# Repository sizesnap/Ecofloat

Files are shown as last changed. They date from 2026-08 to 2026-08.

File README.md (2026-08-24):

# EcoFloat

An autonomous catamaran that maps dissolved oxygen and temperature across a lake and hands back a georeferenced picture of where the water is actually in trouble.

download (1) (1)

Traditional monitoring pulls a handful of point samples and calls it a lake. EcoFloat runs a GPS waypoint mission, logs DO and temperature continuously along the track, and turns that into a spatial map. On its first real survey it found two zones that point sampling would have missed entirely.

---

## Field results — Deep Quarry Lake, July 29 2026

Deep Quarry Lake, West Branch Forest Preserve, DuPage County IL (~40 acres, ~45 ft max depth). Run under a research permit from the Forest Preserve District of DuPage County.

- **2,862** georeferenced DO + temperature readings in a single morning session
- **Low-DO zone** along the northeastern shore, down to **4.72 mg/L**
- **Supersaturation zone** along the western shore, up to **9.75 mg/L**

That's a ~5 mg/L spread across one small lake. A single grab sample anywhere in the middle reports none of it.

DeepQuarry lake Survey map 7_29_2026

---

## How it works



**Navigation** — ArduRover 4.6.3 on a CoreWing F405 Wing V2. Differential skid steer from two ApisQueen U2 12V thrusters driven by DH 40A ESCs. Missions upload as GPS waypoints and run in Auto with no operator input.

**Sensor pod** — ESP32-S3 (Heltec WiFi LoRa 32 V3) polls a DFRobot SEN0680 optical DO sensor over RS485/Modbus, stamps each reading with a fix from a BZ-251 GPS, writes to a 3,000-reading circular buffer on device, and streams telemetry to shore over LoRa.

**Shore station** — a second Heltec V3 receives the LoRa stream and serves a WiFi access point with a Leaflet map: live DO-colored breadcrumbs over satellite imagery, CSV download, and KML mission upload to LittleFS.



**Hull** — custom composite fiberglass layup, twin hulls on a cross-tube bracket system, one 3S LiPo per hull wired in parallel. High-visibility orange and white, because a lost boat 200m out is a bad afternoon.

---

## Bill of materials

Full parts list with quantities, costs, vendor links, and build notes: **[`BOM.csv`](BOM.csv)**

Headline numbers — approximately **$753** total, of which the DFRobot SEN0680 optical DO sensor is $199. Everything else is off-the-shelf hobby-grade hardware or hardware-store consumables.

---|---|---|---|---|
| DFRobot SEN0680 RS485 fluorescence DO sensor (freshwater) | 1 | Dissolved oxygen + temperature, 0–20 mg/L, ModBus-RTU, IP68 | $199 | [DFRobot wiki](https://wiki.dfrobot.com/SKU_SEN0680_RS485_Dissolved_Oxygen_Sensor_Freshwater) · [DigiKey](https://www.digikey.com/en/products/detail/dfrobot/SEN0680/28531158) |
| DFRobot DFR0845 active isolated RS485↔UART adapter | 1 | Bridges the Modbus sensor to the ESP32; supplies 12V to the probe | ~$14 | DFRobot |
| Heltec WiFi LoRa 32 V3 (ESP32-S3 + SX1262) | 2 | Boat sensor pod + shore base station | ~$25 ea | [Heltec](https://heltec.org/project/wifi-lora-32-v3/) · [Rokland](https://store.rokland.com/products/heltec-wifi-lora-32v3) |
| 915 MHz LoRa antenna | 2 | Telemetry link, boat ↔ shore | ~$6 ea | included with board |
| BZ-251 GPS module | 1 | Position fix for each reading | ~$20 | *add your order link* |
| ApisQueen U2 12V underwater thruster (CW + CCW) | 2 | Differential skid-steer propulsion, ~1.7 kg thrust each | ~$85 ea | [ApisQueen](https://www.underwaterthruster.com/products/apisqueen-u2-12v-150w-underwaterthruster-with-esc-5v-1a-bec-output-for-rov-boat) |
| DH 40A bidirectional ESC | 2 | Thruster drive, forward/reverse | ~$20 ea | *add your order link* |
| CoreWing F405 Wing V2 flight controller | 1 | Runs ArduRover 4.6.3, autonomous waypoint navigation | ~$45 | *add your order link* |
| 3S LiPo battery | 2 | One per hull, wired in parallel | ~$30 ea | *add your order link* |
| RadioMaster T8L transmitter + ELRS receiver | 1 | Manual override / failsafe control | ~$45 | *add your order link* |
| Fiberglass cloth + epoxy resin | — | Composite hull layup | ~$60 | local / hardware store |
| Aluminum cross tubes | 2 | Hull-to-hull structure | ~$15 | local / hardware store |
| 3D-printed brackets and electronics trays | — | Resin (Elegoo Saturn 4 Ultra) + FDM; STLs in `hardware/` | ~$10 in resin/filament | printed in-house |
| Marine paint, orange + white | — | High-visibility finish | ~$25 | local / hardware store |

Rough build total: **~$700**, with the DO sensor about a third of it.

---

## Repo layout

```
firmware/
  EcoFloat_Boat/        ESP32-S3 sensor + GPS + LoRa TX
  EcoFloat_Base/        Heltec V3 receiver, web server, Leaflet dashboard
hardware/               CAD sources, STEP, STL
analysis/
  ecofloat_to_kml.py    CSV to Google Earth KML
missions/               KML waypoint mission files
data/                   Survey CSVs
docs/                   Photos, diagrams, build notes
```

Each `.ino` sits in a folder of the same name — an Arduino requirement, so the sketches open cleanly straight from a clone.

---

## Post-processing

`ecofloat_to_kml.py` turns logged CSVs into a Google Earth layer:

```bash
python3 analysis/ecofloat_to_kml.py
```

It auto-discovers CSVs in `~/Downloads/Ecofloat data`, filters GPS jitter and zero-length segments from stationary fixes, and writes KML with color-coded track segments plus a filled disc polygon per reading.

Open the output in **Google Earth Pro (desktop)**. The web version rejects files past its geometry count limit.

---

## Notes from the build

Things that cost real time, recorded so they don't cost anyone else's:

- **Calibrate the compass in its final mounted position.** A bad or missing calibration means Auto mode picks a heading at random the instant you switch into it.
- **Never connect the red BEC wire from an ESC servo lead to the flight controller servo rail.** It backfeeds 5V and causes a power surge. Signal and ground only.
- **DO below ~3.5 mg/L usually means the sensor is out of the water**, not that the lake is dead — that reading is physically impossible in an aerated lake. It's the most reliable air-exposure flag for cleaning merged datasets.
- **The RS485 T/R lines are easy to reverse.** Swapped pins hold the line at ~1V instead of switching cleanly to ground, and the sensor returns zero bytes with no error message at all.
- GPS TX/RX crossover, tube OD tolerances, and hull-to-hull variation in a hand layup all bit at least once. Measure before you print.

---

## Roadmap

- Weekly repeat surveys — Sept 5, 12, 19, 26 and an Oct 10 turnover follow-up, same mission file, same morning window, weather covariates logged each run
- Expansion to Herrick Lake and Rice Lake, pending Forest Preserve coordination
- Additional parameters under evaluation: pH, turbidity, conductivity
- Interpolated heat maps (`scipy.griddata`) plus statistical analysis — ANOVA across zones, regression of DO against temperature and distance from shore

---

## Acknowledgments

Dan Grigas, Fisheries Ecologist at the Forest Preserve District of DuPage County, for the research permit, site access, and ongoing collaboration.

## License

TBD — see repository owner before reuse.

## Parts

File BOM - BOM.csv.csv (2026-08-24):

Item | Qty | Purpose | Unit Cost USD | Line Total USD | Cost Source | Vendor | Link | Notes
DFRobot SEN0680 RS485 Fluorescence Dissolved Oxygen Sensor (Freshwater) | 1 | Dissolved oxygen and temperature, 0-20 mg/L, ModBus-RTU, IP68, 316 stainless probe | 199 | 199 | List price - NOT on cost sheet | DFRobot | https://wiki.dfrobot.com/SKU_SEN0680_RS485_Dissolved_Oxygen_Sensor_Freshwater | Also at DigiKey: https://www.digikey.com/en/products/detail/dfrobot/SEN0680/28531158 . Factory pre-calibrated; zero and full-scale recalibration via register writes.
DFRobot DFR0845 Active Isolated RS485-to-UART Adapter | 1 | Bridges the Modbus DO sensor to the ESP32 and supplies 12V to the probe | 14 | 14 | Estimate - NOT on cost sheet | DFRobot |  | T/R lines are easy to reverse - swapped pins hold the bus at ~1V and the sensor returns zero bytes with no error.
Heltec WiFi LoRa 32 V3 (ESP32-S3 + SX1262) 2-pack | 2 | Boat sensor pod and shore base station | 19.5 | 38.99 | Cost sheet | Heltec | https://store.rokland.com/products/heltec-wifi-lora-32v3 | 915 MHz (US). Flash as generic ESP32S3 Dev Module, Flash Size 8MB, partition scheme with SPIFFS.
915 MHz LoRa antenna | 1 | Telemetry link between boat and shore | 12.99 | 12.99 | Cost sheet
Betian 9th Gen Beidou BK-250P GPS module | 1 | Position fix stamped onto every sensor reading | 29.88 | 29.88 | Cost sheet | Betian |  | TX line to GPIO 26 - avoid GPIO 46, it is a strapping pin and blocks USB uploads.
ApisQueen U2 12V Underwater Thruster (CCW) | 1 | Port-side propulsion, differential skid steer | 43.98 | 43.98 | Cost sheet | ApisQueen | https://www.underwaterthruster.com/products/apisqueen-u2-12v-150w-underwaterthruster-with-esc-5v-1a-bec-output-for-rov-boat | 12-16V (3-4S LiPo), 150W, composite housing, fresh and salt water rated.
ApisQueen U2 12V Underwater Thruster (CW) | 1 | Starboard-side propulsion, differential skid steer | 43.98 | 43.98 | Cost sheet | ApisQueen | https://www.underwaterthruster.com/products/apisqueen-u2-12v-150w-underwaterthruster-with-esc-5v-1a-bec-output-for-rov-boat
DH 40A bidirectional ESC | 2 | Thruster drive, forward and reverse | 21.99 | 43.98 | Cost sheet |  |  | Do NOT connect the red BEC wire from the servo lead to the FC servo rail - it backfeeds 5V. Signal and ground only.
CoreWing F405 Wing V2 flight controller | 1 | Runs ArduRover 4.6.3, autonomous GPS waypoint missions | 45 | 45 | Estimate - NOT on cost sheet |  |  | Compass must be calibrated in its final mounted position or Auto mode picks a random heading on mode switch.
3S LiPo battery (propulsion) | 2 | One per hull, wired in parallel | 30 | 60 | Estimate - NOT on cost sheet |  |  | Endurance approximately 45-65 minutes per survey.
LiPo battery (sensor pod) | 1 | Powers the boat-side Heltec V3 | 12.99 | 12.99 | Cost sheet
RadioMaster T8L transmitter + ELRS receiver | 1 | Manual override and failsafe control | 45 | 45 | Estimate - NOT on cost sheet
Wire | 1 | Power and signal harness throughout the vessel | 29 | 29 | Cost sheet
Screws and fasteners | 1 | Hull assembly and component mounting | 28.99 | 28.99 | Cost sheet
Metal rods | 1 | Structural spars and mounts | 8.49 | 8.49 | Cost sheet
Rope | 1 | Tether and recovery line | 15 | 15 | Cost sheet
Fiberglass cloth | 1 | Hull layup outer shell | 18 | 18 | Cost sheet | Local / hardware store |  | Expect hull-to-hull dimensional variation in a hand layup.
Epoxy resin and hardener | 1 | Hull layup, 5:1 resin to hardener, ~1 hour working time | 66 | 66 | Cost sheet | Local / hardware store |  | Peel ply as the final sacrificial layer makes sanding far easier once cured.
Plywood (1/4 inch) | 1 | Hull side panels over the printed bilge | 20 | 20 | Estimate - NOT on cost sheet | Local / hardware store
Fairing compound | 1 | Fills voids between plywood and printed bilge before layup | 25 | 25 | Estimate - NOT on cost sheet | Local / hardware store
3D printing resin and filament | 1 | Printed bilge sections, brackets, electronics trays, thruster mounts | 30 | 30 | Estimate - NOT on cost sheet | Printed in-house |  | Elegoo Saturn 4 Ultra resin plus FDM. Source CAD and STLs in hardware/.
Marine paint - orange and white | 1 | High-visibility finish | 25 | 25 | Estimate - NOT on cost sheet | Local / hardware store |  | Visibility matters at 200 m from shore.
TOTAL |  |  |  | 855.27 |  |  |  | $392.27 verified against the project cost sheet; the remainder is estimated and needs confirming.

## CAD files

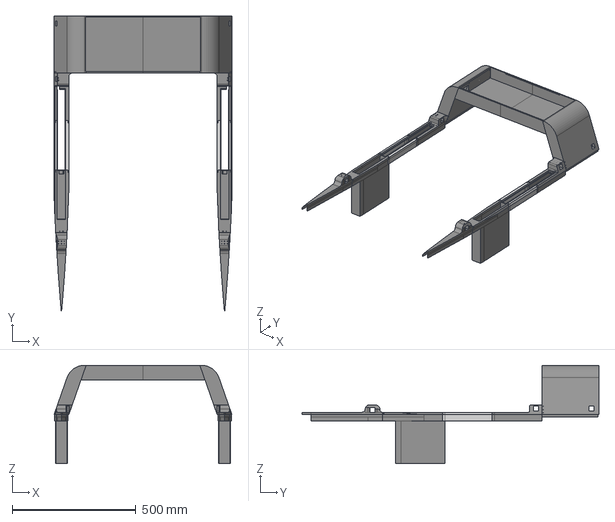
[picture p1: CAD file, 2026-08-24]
Main body.step
720.0 x 1200.0 x 398.0 mm

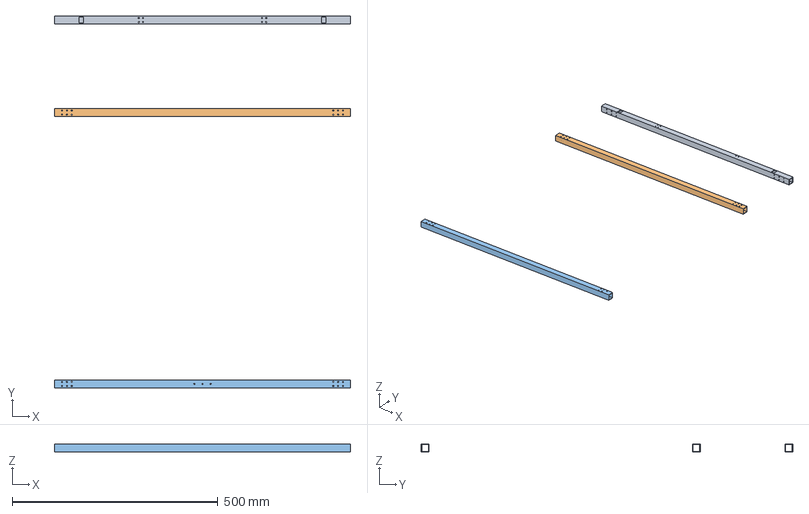
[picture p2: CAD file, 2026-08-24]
Beams.step
720.0 x 904.0 x 19.1 mm

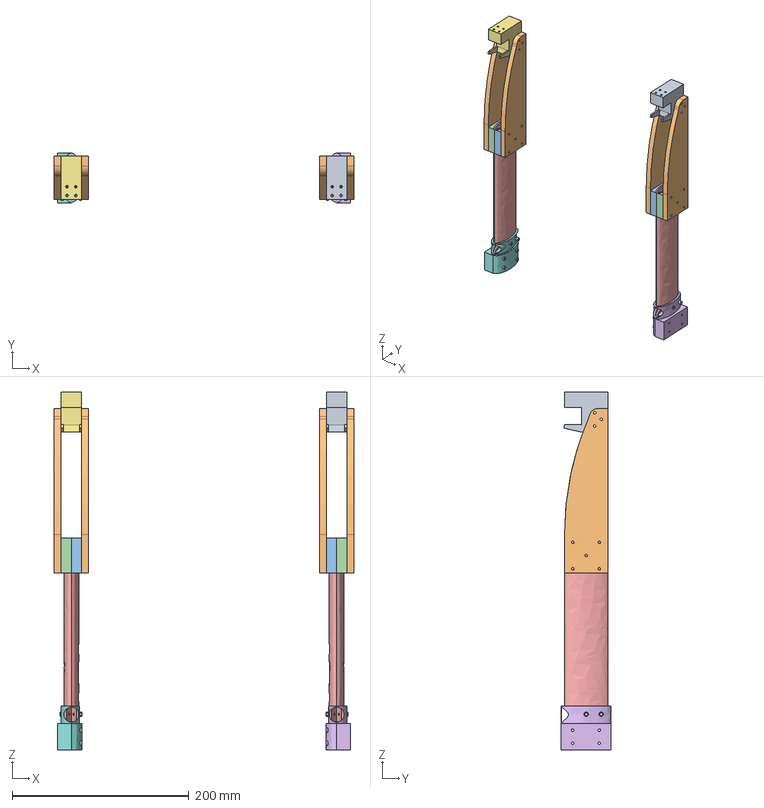
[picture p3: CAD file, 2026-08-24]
Motor Mount.step
339.0 x 56.2 x 405.0 mm
Motor Mount Left
Motor Mount Right

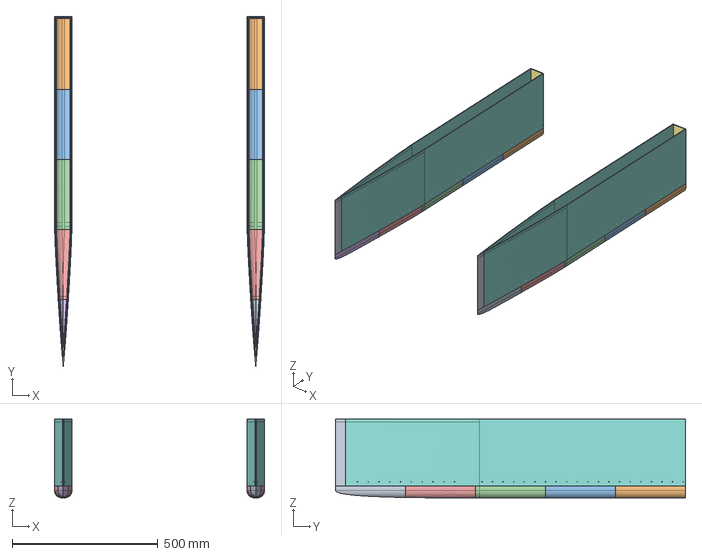
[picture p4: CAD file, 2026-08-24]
Hull.step
720.0 x 1200.0 x 270.0 mm
HullR
HullL

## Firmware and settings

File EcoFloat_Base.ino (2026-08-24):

/*
 * EcoFloat — Base Station (FINAL + on-device CSV log + KML mission nav)
 * Board: Heltec WiFi LoRa 32 V3
 * LoRa params mirror boat v3: SF9, CR 4/7, sync 0x12, preamble 8
 * Dashboard: connect to WiFi "EcoFloat-Base" (pw 12345678) -> http://192.168.4.1
 *
 * FEATURES:
 *   - Receives LoRa telemetry from the boat (position + DO/temp sensors).
 *   - Circular buffer logs every packet on-device (LOG_CAPACITY readings).
 *   - /csv streams the FULL log as a CSV download (survives page refresh /
 *     phone disconnect; lost only on base-station power cycle).
 *   - Live satellite map (Leaflet + Esri World Imagery) with the boat's
 *     position and a DO-colored breadcrumb trail. Satellite tiles need
 *     internet on YOUR PHONE (cellular works while joined to EcoFloat-Base).
 *     With no signal the map shows a notice; the offline SVG trail still works.
 *   - Leaflet + toGeoJSON load ASYNC so no missing-internet stall.
 *   - KML MISSION UPLOAD. Upload a waypoint KML (drawn in Google Earth)
 *     from the dashboard. It's stored on LittleFS (survives reboots) and
 *     parsed in the browser with toGeoJSON. Waypoints draw on the satellite
 *     map as a numbered, dashed route.
 *   - SEMI-ASSISTED WAYPOINT NAV. A nav panel shows the compass bearing
 *     to the active waypoint, distance, course-over-ground (derived from
 *     consecutive GPS fixes — the boat has no magnetometer), and a relative
 *     turn arrow ("turn left 20 deg"). Auto-advances to the next waypoint
 *     within ARRIVE_M metres; tap a chip to jump the target manually.
 */

#include <RadioLib.h>
#include <SPI.h>
#include <WiFi.h>
#include <WebServer.h>
#include <Wire.h>
#include <U8g2lib.h>
#include <LittleFS.h>   // persistent storage for the uploaded KML mission

// ---------------- OLED ----------------
U8G2_SSD1306_128X64_NONAME_F_HW_I2C oled(U8G2_R0, /*reset=*/21, /*clock=*/18, /*data=*/17);
#define VEXT_CTRL 36

// ---------------- LoRa ----------------
SX1262 radio = new Module(8, 14, 12, 13);
volatile bool receivedFlag = false;

// ---------------- WiFi AP ----------------
const char* ssid = "EcoFloat-Base";
const char* password = "12345678";

WebServer server(80);

// ---------------- Latest data ----------------
char  vesselId[16] = "";
unsigned long seqNum = 0;
char  pktDate[12] = "";
char  pktTime[10] = "";
bool  gpsFix = false;
float currentLat = 0.0f, currentLng = 0.0f, currentHdop = 99.9f;
int   currentSat = 0;
float currentDO = -1.0f, currentOS = -1.0f, currentWT = -99.0f;
bool  hasData = false;
unsigned long lastPacketMs = 0;
unsigned long packetCount = 0;

unsigned long lastDisplayMs = 0;
const unsigned long DISPLAY_INTERVAL_MS = 500;

// ---------------- Uploaded mission (KML) ----------------
// The raw KML is stored on LittleFS at /mission.kml so it survives reboots.
// The ESP32 never parses it — the browser does, with toGeoJSON.
bool hasKml = false;      // is a mission file present?
File uploadFile;          // handle used during upload streaming

// ---------------- On-device reading log ----------------
// ~44 bytes/reading x 3000 = ~132 KB static RAM. Fine on the ESP32-S3.
// At the 6 s TX interval this holds ~5 hours of survey history.
#define LOG_CAPACITY 3000

struct Reading {
  uint32_t seq;
  char     date[11];   // "2026-07-19"
  char     time[9];    // "15:03:22"
  bool     fix;
  float    lat, lng;
  uint8_t  sat;
  float    hdop;
  float    dox, os, wt;
};

Reading  logBuf[LOG_CAPACITY];
uint16_t logCount = 0;   // number of valid entries (caps at LOG_CAPACITY)
uint16_t logHead  = 0;   // next write slot

void logReading(unsigned long seq) {
  Reading &r = logBuf[logHead];
  r.seq = (uint32_t)seq;
  strncpy(r.date, pktDate, sizeof(r.date) - 1); r.date[sizeof(r.date) - 1] = '\0';
  strncpy(r.time, pktTime, sizeof(r.time) - 1); r.time[sizeof(r.time) - 1] = '\0';
  r.fix  = gpsFix;
  r.lat  = currentLat;
  r.lng  = currentLng;
  r.sat  = (uint8_t)currentSat;
  r.hdop = currentHdop;
  r.dox  = currentDO;
  r.os   = currentOS;
  r.wt   = currentWT;

  logHead = (logHead + 1) % LOG_CAPACITY;
  if (logCount < LOG_CAPACITY) logCount++;
}

#if defined(ESP8266)
  #define ISR_ATTR ICACHE_RAM_ATTR
#elif defined(ESP32)
  #define ISR_ATTR IRAM_ATTR
#else
  #define ISR_ATTR
#endif

void ISR_ATTR setFlag() { receivedFlag = true; }

// Parses: EF1,seq,date,time,lat,lng,sats,hdop,DO,sat%,temp
bool parsePacket(const String& data) {
  char id[16]; unsigned long seq; char d[12]; char t[10];
  float lat, lng, hdop, dox, os, wt; int sat;
  int n = sscanf(data.c_str(),
    "%15[^,],%lu,%11[^,],%9[^,],%f,%f,%d,%f,%f,%f,%f",
    id, &seq, d, t, &lat, &lng, &sat, &hdop, &dox, &os, &wt);
  if (n != 11) return false;

  strncpy(vesselId, id, sizeof(vesselId) - 1);
  strncpy(pktDate, d, sizeof(pktDate) - 1);
  strncpy(pktTime, t, sizeof(pktTime) - 1);
  seqNum = seq;
  gpsFix = !(lat == 0.0f && lng == 0.0f);
  if (gpsFix) {
    currentLat = lat; currentLng = lng;
  }
  currentHdop = hdop;
  currentSat = sat;
  currentDO = dox; currentOS = os; currentWT = wt;

  hasData = true;
  lastPacketMs = millis();
  packetCount++;

  logReading(seq);   // persist to on-device log
  return true;
}

// ---------------- OLED ----------------
void initOLED() {
  pinMode(VEXT_CTRL, OUTPUT);
  digitalWrite(VEXT_CTRL, LOW);
  delay(100);
  pinMode(21, OUTPUT);
  digitalWrite(21, LOW); delay(20);
  digitalWrite(21, HIGH); delay(20);
  oled.begin();
  oled.setFontPosTop();
}

void drawSplash(const char* ip) {
  oled.clearBuffer();
  oled.setFont(u8g2_font_6x10_tr);
  oled.drawStr(0, 0,  "EcoFloat Base");
  oled.drawHLine(0, 11, 128);
  oled.drawStr(0, 16, "AP: EcoFloat-Base");
  oled.drawStr(0, 28, "IP:");
  oled.drawStr(20, 28, ip);
  oled.drawStr(0, 44, "Waiting for LoRa...");
  oled.sendBuffer();
}

void updateOLED() {
  oled.clearBuffer();
  oled.setFont(u8g2_font_6x10_tr);
  oled.drawStr(0, 0, "EcoFloat RX");
  char rxStr[16];
  snprintf(rxStr, sizeof(rxStr), "Pkt:%lu", packetCount);
  oled.drawStr(74, 0, rxStr);
  oled.drawHLine(0, 11, 128);

  if (!hasData) {
    oled.drawStr(0, 28, "Waiting for data...");
    oled.sendBuffer();
    return;
  }

  char buf[24];
  if (gpsFix) {
    snprintf(buf, sizeof(buf), "Lat:%.5f", currentLat);
    oled.drawStr(0, 15, buf);
    snprintf(buf, sizeof(buf), "Lng:%.5f", currentLng);
    oled.drawStr(0, 26, buf);
  } else {
    oled.drawStr(0, 15, "GPS: no fix");
    snprintf(buf, sizeof(buf), "Searching, sats:%d", currentSat);
    oled.drawStr(0, 26, buf);
  }

  if (currentDO >= 0) snprintf(buf, sizeof(buf), "DO:%.2f  T:%.1fC", currentDO, currentWT);
  else                snprintf(buf, sizeof(buf), "DO:--    T:--");
  oled.drawStr(0, 37, buf);

  unsigned long ageSec = (millis() - lastPacketMs) / 1000UL;
  snprintf(buf, sizeof(buf), "Log:%u  Age:%lus", logCount, ageSec);
  oled.drawStr(0, 48, buf);

  if (ageSec < 15)      oled.drawBox(0, 60, 128, 4);
  else if (ageSec < 40) oled.drawFrame(0, 60, 128, 4);
  else                  for (int x = 0; x < 128; x += 6) oled.drawHLine(x, 62, 3);

  oled.sendBuffer();
}

// ---------------- Dashboard page ----------------
const char PAGE[] PROGMEM = R"GPSWEB(<!DOCTYPE html>
<html>
<head>
<meta charset="utf-8">
<meta name="viewport" content="width=device-width,initial-scale=1">
<title>EcoFloat live</title>
<style>
body{font-family:-apple-system,'Segoe UI',Roboto,sans-serif;margin:0;background:#0d1622;color:#e9eef5}
header{display:flex;justify-content:space-between;align-items:center;padding:12px 16px;border-bottom:1px solid #20304a}
h1{font-size:18px;margin:0}
.sub{font-size:12px;color:#8fa3c0}
.dot{display:inline-block;width:10px;height:10px;border-radius:50%;background:#e67e22;margin-right:6px;vertical-align:middle}
.grid{display:grid;grid-template-columns:repeat(auto-fit,minmax(150px,1fr));gap:10px;padding:12px;max-width:900px;margin:0 auto}
.card{background:#16233a;border-radius:12px;padding:14px;text-align:center}
.lbl{font-size:11px;letter-spacing:.08em;text-transform:uppercase;color:#8fa3c0;margin-bottom:4px}
.val{font-size:30px;font-weight:700;line-height:1.1}
.unit{font-size:13px;color:#8fa3c0}
#doCard{grid-column:1/-1;padding:20px}
#doVal{font-size:56px}
#doBand{display:inline-block;margin-top:8px;padding:4px 14px;border-radius:999px;font-size:13px;font-weight:600;background:#2c3e57;color:#cfe0f5}
.section{max-width:900px;margin:0 auto;padding:0 12px 12px}
.panel{background:#16233a;border-radius:12px;padding:12px}
table{width:100%;border-collapse:collapse;font-size:12.5px}
th,td{padding:5px 6px;text-align:right;border-bottom:1px solid #20304a}
th:first-child,td:first-child{text-align:left}
button{background:#2563eb;color:#fff;border:0;border-radius:8px;padding:8px 14px;font-size:13px;cursor:pointer}
button.alt{background:#178a5b}
.btnrow{display:flex;gap:8px;flex-wrap:wrap;align-items:center}
/* SCOPED to #trail — a bare svg{} rule here overrides Leaflet's own SVG
   renderer and silently kills the KML route polylines on the map. */
#trail{width:100%;height:300px;display:block}
#map{height:340px;border-radius:10px;background:#0a111c}
#mapNote{font-size:12px;color:#8fa3c0;margin-top:6px;display:none}
.maphdr{display:flex;justify-content:space-between;align-items:center;margin-bottom:6px;flex-wrap:wrap;gap:8px}
.legend{display:flex;gap:12px;font-size:11.5px;color:#8fa3c0;flex-wrap:wrap;margin-top:6px}
.sw{display:inline-block;width:10px;height:10px;border-radius:3px;margin-right:4px;vertical-align:middle}
/* --- waypoint navigation panel --- */
#navPanel{display:none;background:#16233a;border-radius:12px;padding:16px;margin:0 auto 12px;max-width:900px}
#navBig{font-size:40px;font-weight:800;line-height:1.05}
#navSub{font-size:13px;color:#8fa3c0;margin-top:4px}
.navrow{display:flex;gap:16px;align-items:center;flex-wrap:wrap}
.navstat{flex:1;min-width:120px}
.navstat .lbl{margin-bottom:2px}
.navstat .v{font-size:24px;font-weight:700}
#wpChips{display:flex;gap:6px;flex-wrap:wrap;margin-top:10px}
.chip{padding:3px 9px;border-radius:999px;font-size:12px;background:#2c3e57;color:#cfe0f5;cursor:pointer}
.chip.active{background:#f1c40f;color:#10202e}
.chip.done{background:#178a5b;color:#dff5ea}
.arrow{font-size:34px;display:inline-block;transition:transform .3s}
</style>
</head>
<body>
<header>
<div><h1>EcoFloat live</h1><div class="sub" id="vessel">waiting for vessel...</div></div>
<div class="sub"><span class="dot" id="linkDot"></span><span id="linkTxt">connecting...</span></div>
</header>

<div class="grid">
<div class="card" id="doCard">
<div class="lbl">dissolved oxygen</div>
<div class="val" id="doVal">--</div>
<div class="unit">mg/L</div><br>
<div id="doBand">waiting for data</div>
</div>
<div class="card"><div class="lbl">saturation</div><div class="val" id="osVal">--</div><div class="unit">%</div></div>
<div class="card"><div class="lbl">water temp</div><div class="val" id="wtVal">--</div><div class="unit" id="wtF">&deg;C</div></div>
<div class="card"><div class="lbl">satellites</div><div class="val" id="satVal">--</div><div class="unit" id="fixTxt">no fix</div></div>
<div class="card"><div class="lbl">gps accuracy</div><div class="val" id="hdopVal">--</div><div class="unit" id="hdopQ">HDOP</div></div>
</div>

<!-- waypoint navigation panel -->
<div class="section"><div id="navPanel">
<div class="navrow">
<div style="text-align:center;min-width:90px">
<div class="arrow" id="navArrow">&uarr;</div>
<div class="lbl" style="margin-top:2px">relative</div>
</div>
<div style="flex:2;min-width:160px">
<div class="lbl">steer toward waypoint <span id="wpIdx">1</span></div>
<div id="navBig">--&deg;</div>
<div id="navSub">acquiring position...</div>
</div>
<div class="navstat">
<div class="lbl">distance</div><div class="v" id="navDist">--</div>
</div>
<div class="navstat">
<div class="lbl">boat heading (COG)</div><div class="v" id="navCog">--</div>
</div>
</div>
<div id="wpChips"></div>
</div></div>

<div class="section"><div class="panel">
<div class="maphdr">
<div class="lbl" style="margin:0">satellite map &middot; live position</div>
<div class="btnrow">
<label style="font-size:12px;color:#8fa3c0;cursor:pointer"><input type="checkbox" id="followChk" checked> follow</label>
<input type="file" id="kmlFile" accept=".kml" style="display:none" onchange="uploadKml(this)">
<button onclick="document.getElementById('kmlFile').click()">Upload KML</button>
<button class="alt" id="clearBtn" onclick="clearKml()" style="display:none">Clear</button>
</div>
</div>
<div id="map"></div>
<div id="mapNote">satellite map needs internet (your phone's cellular data). Still loading or no connection &mdash; live data works regardless; use the trail view below.</div>
</div></div>

<div class="section"><div class="panel">
<div class="lbl">survey trail &middot; colored by DO</div>
<svg id="trail" viewBox="0 0 600 300" preserveAspectRatio="xMidYMid meet"></svg>
<div class="legend">
<span><span class="sw" style="background:#2ecc71"></span>&ge;6 good</span>
<span><span class="sw" style="background:#f1c40f"></span>4&ndash;6 fair</span>
<span><span class="sw" style="background:#e67e22"></span>2&ndash;4 low</span>
<span><span class="sw" style="background:#e74c3c"></span>&lt;2 hypoxic</span>
</div>
</div></div>

<div class="section"><div class="panel">
<div style="display:flex;justify-content:space-between;align-items:center;margin-bottom:6px;flex-wrap:wrap;gap:8px">
<div class="lbl" style="margin:0">readings logged: <span id="nPts">0</span> (base station: <span id="nLog">0</span>)</div>
<div class="btnrow">
<button onclick="dlCSV()">CSV (this session)</button>
<button class="alt" onclick="location.href='/csv'">Full log CSV</button>
</div>
</div>
<table><thead><tr><th>time (UTC)</th><th>lat</th><th>lng</th><th>DO</th><th>%</th><th>&deg;C</th></tr></thead>
<tbody id="rows"></tbody></table>
</div></div>

<script>
let pts=[],lastSeq=-1;

// mission state
let waypoints=[];       // [{lat,lng,name}]
let activeWp=0;         // index of the waypoint we're driving to
let wpLayer=null;       // Leaflet layer group for the drawn mission
let tgjReady=false, pendingKmlLoad=false;
let prevFix=null;       // previous GPS fix, for course-over-ground
const ARRIVE_M=8;       // waypoint considered reached within this many metres

// ---------- satellite map (loaded async so it can NEVER block the dashboard) ----------
let map=null,boatMarker=null,mapReady=false,tilesOK=false;
function loadLeaflet(){
const css=document.createElement('link');
css.rel='stylesheet';css.href='https://unpkg.com/leaflet@1.9.4/dist/leaflet.css';
document.head.appendChild(css);
const js=document.createElement('script');
js.src='https://unpkg.com/leaflet@1.9.4/dist/leaflet.js';
js.async=true;
js.onload=initMap;
js.onerror=function(){document.getElementById('mapNote').style.display='block';};
document.head.appendChild(js);
setTimeout(function(){if(!mapReady)document.getElementById('mapNote').style.display='block';},8000);
}
// load toGeoJSON (async, never blocks); when ready, load any stored mission
function loadToGeoJSON(){
const s=document.createElement('script');
s.src='https://unpkg.com/@tmcw/togeojson@5.8.1/dist/togeojson.umd.js';
s.async=true;
s.onload=function(){tgjReady=true;if(pendingKmlLoad)fetchMission();};
document.head.appendChild(s);
}
function initMap(){
if(typeof L==='undefined'){document.getElementById('mapNote').style.display='block';return;}
map=L.map('map',{zoomControl:true,attributionControl:true}).setView([41.916,-88.234],15);
const sat=L.tileLayer('https://server.arcgisonline.com/ArcGIS/rest/services/World_Imagery/MapServer/tile/{z}/{y}/{x}',{maxZoom:19,attribution:'Imagery &copy; Esri'});
sat.on('tileload',function(){tilesOK=true;document.getElementById('mapNote').style.display='none';});
sat.on('tileerror',function(){if(!tilesOK)document.getElementById('mapNote').style.display='block';});
sat.addTo(map);
const boatIcon=L.divIcon({className:'',html:'<div style="width:18px;height:18px;border-radius:50%;background:#2563eb;border:3px solid #fff;box-shadow:0 0 8px rgba(0,0,0,.6)"></div>',iconSize:[18,18],iconAnchor:[9,9]});
boatMarker=L.marker([41.916,-88.234],{icon:boatIcon,zIndexOffset:1000});
mapReady=true;
document.getElementById('mapNote').style.display='none';
pts.forEach(mapAddPoint);
// draw a mission that arrived before the map finished loading
if(waypoints.length)drawMission();else{pendingKmlLoad=true;if(tgjReady)fetchMission();}
}
function mapAddPoint(p){
if(!mapReady||!p.fix)return;
if(!boatMarker._map){boatMarker.addTo(map);map.setView([p.lat,p.lng],17);}
boatMarker.setLatLng([p.lat,p.lng]);
if(p.dox>=0){L.circleMarker([p.lat,p.lng],{radius:5,color:'#0d1622',weight:1,fillColor:band(p.dox)[0],fillOpacity:.9}).bindTooltip('DO '+p.dox.toFixed(2)+' mg/L &middot; '+p.time).addTo(map);}
if(document.getElementById('followChk').checked)map.panTo([p.lat,p.lng]);
}
function band(d){return d>=6?['#2ecc71','good - most fish thrive']:d>=4?['#f1c40f','fair - sensitive fish stressed']:d>=2?['#e67e22','low - many fish stressed']:['#e74c3c','hypoxic - fish at risk'];}
function hq(h){return h<=1.5?'HDOP - excellent':h<=2.5?'HDOP - good':h<=5?'HDOP - fair':'HDOP - poor';}
function fmt(v,n){return (v==null||v<0)?'--':v.toFixed(n);}

// ---------- navigation math ----------
function toRad(d){return d*Math.PI/180;}
function toDeg(r){return r*180/Math.PI;}
function distM(a,b){
const R=6371000,p1=toRad(a.lat),p2=toRad(b.lat);
const dp=toRad(b.lat-a.lat),dl=toRad(b.lng-a.lng);
const x=Math.sin(dp/2)*Math.sin(dp/2)+Math.cos(p1)*Math.cos(p2)*Math.sin(dl/2)*Math.sin(dl/2);
return 2*R*Math.asin(Math.sqrt(x));
}
function bearing(a,b){
const p1=toRad(a.lat),p2=toRad(b.lat),dl=toRad(b.lng-a.lng);
const y=Math.sin(dl)*Math.cos(p2);
const x=Math.cos(p1)*Math.sin(p2)-Math.sin(p1)*Math.cos(p2)*Math.cos(dl);
return (toDeg(Math.atan2(y,x))+360)%360;
}
function compass(deg){
const d=['N','NNE','NE','ENE','E','ESE','SE','SSE','S','SSW','SW','WSW','W','WNW','NW','NNW'];
return d[Math.round(deg/22.5)%16];
}
function fmtDist(m){return m>=1000?(m/1000).toFixed(2)+' km':m.toFixed(0)+' m';}

// ---------- mission upload / clear ----------
function uploadKml(input){
const f=input.files[0];if(!f)return;
const fd=new FormData();fd.append('file',f);
fetch('/upload',{method:'POST',body:fd})
.then(function(){pendingKmlLoad=true;if(tgjReady)fetchMission();})
.catch(function(){alert('upload failed - still connected to EcoFloat-Base?');});
input.value='';
}
function clearKml(){
fetch('/clearkml').then(function(){
waypoints=[];activeWp=0;
if(wpLayer&&map){map.removeLayer(wpLayer);wpLayer=null;}
document.getElementById('navPanel').style.display='none';
document.getElementById('clearBtn').style.display='none';
document.getElementById('wpChips').innerHTML='';
});
}

// ---------- fetch stored KML, parse in the browser ----------
function fetchMission(){
pendingKmlLoad=false;
fetch('/kml').then(function(r){if(!r.ok)throw 0;return r.text();})
.then(function(txt){
const dom=new DOMParser().parseFromString(txt,'text/xml');
const gj=toGeoJSON.kml(dom);
waypoints=[];
gj.features.forEach(function(ft){
const g=ft.geometry;if(!g)return;
const nm=(ft.properties&&ft.properties.name)||'';
if(g.type==='Point'){
waypoints.push({lng:g.coordinates[0],lat:g.coordinates[1],name:nm});
}else if(g.type==='LineString'){
g.coordinates.forEach(function(c,i){waypoints.push({lng:c[0],lat:c[1],name:nm?(nm+' '+(i+1)):''});});
}
});
activeWp=0;
drawMission();
if(waypoints.length){
document.getElementById('navPanel').style.display='block';
document.getElementById('clearBtn').style.display='inline-block';
}
})
.catch(function(){/* no mission yet - fine */});
}

// ---------- draw waypoints + route on the map ----------
function drawMission(){
if(!mapReady)return;
if(wpLayer)map.removeLayer(wpLayer);
wpLayer=L.layerGroup().addTo(map);
const latlngs=waypoints.map(function(w){return [w.lat,w.lng];});
if(latlngs.length>1)L.polyline(latlngs,{color:'#f1c40f',weight:2,dashArray:'6 5',opacity:.9}).addTo(wpLayer);
waypoints.forEach(function(w,i){
const ic=L.divIcon({className:'',html:'<div style="width:22px;height:22px;border-radius:50%;background:'+(i===activeWp?'#f1c40f':'#2c3e57')+';border:2px solid #fff;color:'+(i===activeWp?'#10202e':'#fff')+';font:700 12px sans-serif;display:flex;align-items:center;justify-content:center">'+(i+1)+'</div>',iconSize:[22,22],iconAnchor:[11,11]});
L.marker([w.lat,w.lng],{icon:ic}).bindTooltip('WP'+(i+1)+(w.name?' - '+w.name:'')).addTo(wpLayer);
});
if(latlngs.length&&map)map.fitBounds(L.latLngBounds(latlngs).pad(0.3));
drawChips();
}
function drawChips(){
document.getElementById('wpChips').innerHTML=waypoints.map(function(w,i){
const cls=i<activeWp?'chip done':(i===activeWp?'chip active':'chip');
return '<span class="'+cls+'" onclick="setActive('+i+')">WP'+(i+1)+'</span>';
}).join('');
}
function setActive(i){activeWp=i;drawMission();}

// ---------- nav update, called on each new fix ----------
function updateNav(lat,lng){
if(!waypoints.length||activeWp>=waypoints.length)return;
const boat={lat:lat,lng:lng};
const tgt=waypoints[activeWp];
const d=distM(boat,tgt);
const brg=bearing(boat,tgt);

if(d<=ARRIVE_M){
activeWp++;
drawMission();
if(activeWp>=waypoints.length){
document.getElementById('navBig').textContent='DONE';
document.getElementById('navSub').textContent='all waypoints reached';
document.getElementById('navDist').textContent='--';
document.getElementById('navArrow').style.transform='';
return;
}
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
void loop() {
  server.handleClient();

  bool packetReady = false;
  noInterrupts();
  if (receivedFlag) { receivedFlag = false; packetReady = true; }
  interrupts();

  if (packetReady) {
    String data;
    int state = radio.readData(data);
    if (state == RADIOLIB_ERR_NONE) {
      Serial.print("Received: "); Serial.println(data);
      if (!parsePacket(data)) Serial.println("Invalid packet format.");
    } else {
      Serial.print("LoRa read error: "); Serial.println(state);
    }
    radio.startReceive();
  }

  if (millis() - lastDisplayMs >= DISPLAY_INTERVAL_MS) {
    lastDisplayMs = millis();
    updateOLED();
  }
}

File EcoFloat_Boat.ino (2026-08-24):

/*
 * EcoFloat — Boat Node (v3 FINAL, 6s survey interval)
 * Board: Heltec WiFi LoRa 32 V3 (ESP32-S3 + SX1262)
 *
 * Fixes from v2:
 *   - setDio2AsRfSwitch(true): the V3 routes its RF switch through DIO2.
 *     Without it the radio reports TX success but barely radiates.
 *   - Explicit SPI pin mapping for the radio bus.
 *   - 2KB GPS RX buffer so NMEA survives the DO retry window.
 *
 * Changes in this version:
 *   - TX interval set to 6s (was 2s). Lower duty cycle = less radio power
 *     burned, less LoRa airtime, and a much longer on-device log at the
 *     base station (3000 readings now covers ~5 hours instead of ~100 min).
 *   - DO sensor timeout remains 700ms, comfortably under the 6s cycle
 *     budget so a failed sensor read can never starve GPS parsing or TX.
 *
 * Wiring:
 *   GPS:    VCC->3V3, GND->GND, GPS TX -> GPIO 26
 *   RS485:  VCC->3V3, GND->GND, adapter T -> GPIO 48, adapter R -> GPIO 47
 *   Sensor: brown->12V, black->GND, yellow->A, blue->B
 */

#include <RadioLib.h>
#include <TinyGPSPlus.h>
#include <SPI.h>

// ---------------- Pin assignments ----------------
#define LORA_NSS    8
#define LORA_DIO1   14
#define LORA_RST    12
#define LORA_BUSY   13

#define LORA_SCK    9
#define LORA_MISO   11
#define LORA_MOSI   10

#define GPS_RX_PIN  26
#define GPS_TX_PIN  34
#define GPS_BAUD    9600

#define RS485_RX_PIN 48  // ESP32 RX  <-- adapter "T"
#define RS485_TX_PIN 47  // ESP32 TX  --> adapter "R"
#define RS485_BAUD   4800

// LoRa settings — base station MUST mirror these exactly
#define LORA_FREQ_MHZ   915.0
#define LORA_BW_KHZ     125.0
#define LORA_SF         9
#define LORA_CR         7
#define LORA_SYNC_WORD  0x12
#define LORA_TX_DBM     17
#define LORA_PREAMBLE   8
#define LORA_TCXO_V     1.6

// Survey interval: one reading + TX every 6 seconds
#define TX_INTERVAL_MS  6000UL

// Max time to wait for a DO sensor response before giving up this cycle.
// Well under the TX interval so a dead sensor can't starve GPS/TX.
#define DO_TIMEOUT_MS   700UL

SX1262 radio = new Module(LORA_NSS, LORA_DIO1, LORA_RST, LORA_BUSY);
TinyGPSPlus gps;
HardwareSerial GPSSerial(1);
HardwareSerial DOSerial(2);

uint32_t lastTx = 0;
uint32_t packetCount = 0;

// ---------------- Modbus helpers ----------------
uint16_t modbusCRC(const uint8_t *buf, uint8_t len) {
  uint16_t crc = 0xFFFF;
  for (uint8_t i = 0; i < len; i++) {
    crc ^= buf[i];
    for (uint8_t b = 0; b < 8; b++) {
      if (crc & 0x0001) crc = (crc >> 1) ^ 0xA001;
      else              crc >>= 1;
    }
  }
  return crc;
}

float bytesToFloat(const uint8_t *b) {
  uint32_t v = ((uint32_t)b[0] << 24) | ((uint32_t)b[1] << 16) |
               ((uint32_t)b[2] << 8)  |  (uint32_t)b[3];
  float f;
  memcpy(&f, &v, 4);
  return f;
}

bool readDOSensor(float &doSatPct, float &doMgL, float &tempC) {
  const uint8_t query[8] = {0x01, 0x03, 0x00, 0x00, 0x00, 0x06, 0xC5, 0xC8};
  uint8_t resp[17];
  uint8_t idx = 0;
  uint32_t start = millis();
  uint32_t lastSend = 0;

  while (millis() - start < DO_TIMEOUT_MS) {
    if (millis() - lastSend > 100 && idx == 0) {
      while (DOSerial.available()) DOSerial.read();
      DOSerial.write(query, 8);
      lastSend = millis();
    }
    if (DOSerial.available()) {
      uint8_t b = DOSerial.read();
      if (idx == 0 && b != 0x01) continue;
      resp[idx++] = b;
      if (idx >= sizeof(resp)) break;
    }
  }

  if (idx < sizeof(resp))                                    return false;
  if (resp[0] != 0x01 || resp[1] != 0x03 || resp[2] != 0x0C) return false;
  uint16_t rxCrc = resp[15] | ((uint16_t)resp[16] << 8);
  if (modbusCRC(resp, 15) != rxCrc)                          return false;

  doSatPct = bytesToFloat(&resp[3]) * 100.0f;
  doMgL    = bytesToFloat(&resp[7]);
  tempC    = bytesToFloat(&resp[11]);
  return true;
}

// ---------------- Setup / loop ----------------
void setup() {
  Serial.begin(115200);
  delay(300);
  Serial.println(F("EcoFloat boat node v3 (6s interval) starting..."));

  GPSSerial.setRxBufferSize(2048);   // must come BEFORE begin()
  GPSSerial.begin(GPS_BAUD, SERIAL_8N1, GPS_RX_PIN, GPS_TX_PIN);
  DOSerial.begin(RS485_BAUD, SERIAL_8N1, RS485_RX_PIN, RS485_TX_PIN);

  SPI.begin(LORA_SCK, LORA_MISO, LORA_MOSI, LORA_NSS);

  int state = radio.begin(LORA_FREQ_MHZ, LORA_BW_KHZ, LORA_SF, LORA_CR,
                          LORA_SYNC_WORD, LORA_TX_DBM, LORA_PREAMBLE,
                          LORA_TCXO_V, false);
  if (state != RADIOLIB_ERR_NONE) {
    Serial.print(F("LoRa init failed, code "));
    Serial.println(state);
    while (true) delay(1000);
  }

  radio.setDio2AsRfSwitch(true);   // CRITICAL on Heltec V3
  Serial.println(F("LoRa init OK"));
}

void loop() {
  while (GPSSerial.available()) {
    gps.encode(GPSSerial.read());
  }

  if (millis() - lastTx < TX_INTERVAL_MS) return;
  lastTx = millis();

  float doSat = NAN, doMgL = NAN, tempC = NAN;
  bool doOK = readDOSensor(doSat, doMgL, tempC);
  if (doOK) {
    Serial.printf("[DO] %.2f mg/L | %.1f%% | %.2f C\n", doMgL, doSat, tempC);
  } else {
    Serial.println(F("WARN: DO sensor read failed"));
  }

  char date[12] = "0000-00-00";
  char tim[10]  = "00:00:00";
  double lat = 0.0, lng = 0.0;
  int sats = 0;
  float hdop = 99.9;

  if (gps.location.isValid()) {
    lat = gps.location.lat();
    lng = gps.location.lng();
  }
  if (gps.date.isValid()) {
    snprintf(date, sizeof(date), "%04u-%02u-%02u",
             gps.date.year(), gps.date.month(), gps.date.day());
  }
  if (gps.time.isValid()) {
    snprintf(tim, sizeof(tim), "%02u:%02u:%02u",
             gps.time.hour(), gps.time.minute(), gps.time.second());
  }
  if (gps.satellites.isValid()) sats = gps.satellites.value();
  if (gps.hdop.isValid())       hdop = gps.hdop.hdop();

  packetCount++;
  char packet[160];
  snprintf(packet, sizeof(packet),
           "EF1,%lu,%s,%s,%.6f,%.6f,%d,%.1f,%.2f,%.1f,%.2f",
           (unsigned long)packetCount, date, tim, lat, lng, sats, hdop,
           doOK ? doMgL : -1.0f,
           doOK ? doSat : -1.0f,
           doOK ? tempC : -99.0f);

  Serial.print(F("TX: "));
  Serial.println(packet);

  int state = radio.transmit(packet);
  if (state != RADIOLIB_ERR_NONE) {
    Serial.print(F("LoRa TX failed, code "));
    Serial.println(state);
  }
}
